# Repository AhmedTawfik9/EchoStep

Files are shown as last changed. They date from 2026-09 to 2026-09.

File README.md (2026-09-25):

# EchoStep – Feedback Device for Special Needs

EchoStep is a wearable assistive system developed.

The project is designed to support people with hearing impairments by detecting environmental sounds, estimating their direction and intensity, and converting this information into visual feedback on a wearable device.

## Features

- Real-time sound level detection using an Android smartphone
- Stereo-audio based sound direction estimation
- TDOA / GCC-PHAT based sound localization
- Classification of sound direction as LEFT, CENTER or RIGHT
- Sound intensity estimation
- Bluetooth Low Energy (BLE) communication
- Arduino Nano 33 BLE based wearable controller
- LED matrix / RGB visual feedback
- Step counter functionality
- Custom 3D-printed enclosure

## System Architecture

The system consists of three main components:

1. **Android SoundDetector App**
   - Captures audio from the smartphone microphones
   - Calculates sound level
   - Estimates sound direction using stereo audio
   - Uses TDOA and GCC-PHAT for direction estimation
   - Sends the processed information to the wearable device through BLE

2. **Arduino Wearable Device**
   - Based on the Arduino Nano 33 BLE
   - Receives sound information from the Android application
   - Displays sound direction and intensity using LEDs
   - Provides wearable feedback to the user
   - Includes step-counting functionality

3. **3D-Printed Enclosure**
   - Custom enclosure designed for the wearable electronics
   - Contains the Arduino, display/LED components and supporting hardware

## Repository Structure

```text
EchoStep/
├── android-app/     # Android SoundDetector application
├── arduino/         # Arduino firmware
├── 3d-models/       # 3D-printable enclosure files
├── README.md
├── LICENSE
└── .gitignore

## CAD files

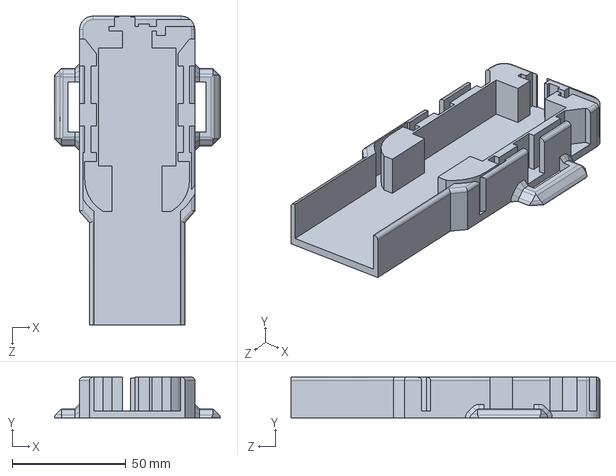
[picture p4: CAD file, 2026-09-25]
3D-Models/Base2.1.SLDPRT
73.1 x 18.0 x 136.0 mm

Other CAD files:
3D-Models/Base2.1.STL

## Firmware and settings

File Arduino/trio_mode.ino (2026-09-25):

/*
  Triple-Mode Wearable Feedback Device
  ----------------------------------------
  Three display modes on a single 8x8 MAX7219 matrix, cycled via the B14
  button (interrupt-driven):

    MODE_STEPS      - step-count progress (onboard IMU)          -> Mode1_Steps.hpp
    MODE_SOUND_BLE  - sound intensity via phone-assisted BLE      -> Mode2_SoundBLE.hpp
    MODE_MIC_ARRAY  - sound direction/intensity, onboard 2-mic    -> Mode3_MicArray.hpp

  Each mode lives entirely in its own file: its own tuning constants,
  state, and update logic, grouped together and documented at the top of
  that file. This file only owns shared hardware (the matrix, the
  button) and orchestration (mode enum, ISR, setup/loop, render dispatch)
  — see each Mode*.hpp file for that mode's specific tuning parameters
  and calibration notes.

  CORE DESIGN PRINCIPLE: every mode's data is updated EVERY loop
  iteration regardless of which mode is currently displayed. Only the
  final "push this mode's buffer to the matrix" step is gated on which
  mode is active (see renderActiveMode() and each mode's own Update()
  function). This keeps all three subsystems "live" in the background,
  so switching modes never loses data.

  The button uses a hardware interrupt only because it's an
  unpredictable, user-triggered event we don't want to risk missing
  (e.g. during the step mode's celebration delay() calls). The ISR
  itself only flips a flag; the actual mode switch and re-render happen
  in loop() — see onButtonPress() and the top of loop().

  Wiring:
  - MAX7219 matrix (SPI): VCC->5V, GND->GND, DIN->D11, CLK->D13, CS->D10
  - B14 button: one leg -> D2 (BUTTON_PIN below), other leg -> GND
    (uses internal pullup, so button press = LOW)
  - Two B03 microphones: MIC1 -> A6 (must be the RIGHT mic), MIC2 -> A7
    (must be the LEFT mic) — see Mode3_MicArray.hpp / SoundDirection.hpp
    for why this physical placement matters.

  NOTE ON MAX7219 POWER: if the matrix shows nothing, the Nano's 3.3V
  logic may be below the MAX7219's input-high threshold when it's
  powered at 5V. Try powering the matrix's VCC from 3.3V instead, or use
  a logic level shifter.
*/

#include <MD_MAX72xx.h>
#include <SPI.h>

// ---------------- MAX7219 matrix configuration ---------------- PAROLA_HW or GENERIC_HW or FC16_HW
#define HARDWARE_TYPE MD_MAX72XX::GENERIC_HW
#define MAX_DEVICES 1
#define CS_PIN 10
MD_MAX72XX mx = MD_MAX72XX(HARDWARE_TYPE, CS_PIN, MAX_DEVICES);

// ---------------- Display mode ----------------
enum DisplayMode { MODE_STEPS, MODE_SOUND_BLE, MODE_MIC_ARRAY, NUM_MODES };
DisplayMode currentMode = MODE_STEPS;

// ---------------- Button configuration ----------------
const int BUTTON_PIN = 2;
const unsigned long DEBOUNCE_MS = 200;
volatile bool modeChangeRequested = false;
volatile unsigned long lastInterruptTime = 0;

void onButtonPress() {
  unsigned long now = millis();
  if (now - lastInterruptTime > DEBOUNCE_MS) {
    modeChangeRequested = true;
    lastInterruptTime = now;
  }
}

// Forward declaration so the mode files (included below) can call this
// from their own Update() functions.
void renderActiveMode();

// ---------------- Mode implementations ----------------
// Each file is self-contained: its own tuning constants, state, and
// logic. See each file's header comment for details specific to that
// mode.
#include "Mode1_Steps.hpp"
#include "Mode2_SoundBLE.hpp"
#include "Mode3_MicArray.hpp"

void setup() {
  Serial.begin(115200);

  // Bounded wait for Serial Monitor rather than an infinite while(!Serial)
  // — lets the sketch proceed even if no Serial connection shows up,
  // instead of hanging forever. This is the ONE Serial wait for the whole
  // sketch; individual mode files do not repeat it.
  unsigned long serialWaitStart = millis();
  while (!Serial && (millis() - serialWaitStart < 3000)) {
    ;
  }

  bool matrixOK = mx.begin();
  mx.control(MD_MAX72XX::INTENSITY, MAX_INTENSITY);
  mx.clear();
  Serial.print("MAX7219 init: ");
  Serial.println(matrixOK ? "OK" : "FAILED");

  pinMode(BUTTON_PIN, INPUT_PULLUP);
  attachInterrupt(digitalPinToInterrupt(BUTTON_PIN), onButtonPress, FALLING);

  stepsSetup();
  soundBLESetup();
  micArraySetup();

  Serial.println("Ready. Starting in STEP mode.");
  renderActiveMode();
}

void loop() {
  // Handle a pending mode switch requested by the ISR
  if (modeChangeRequested) {
    modeChangeRequested = false;
    currentMode = (DisplayMode)((currentMode + 1) % NUM_MODES);

    Serial.print("Switched to mode: ");
    switch (currentMode) {
      case MODE_STEPS:     Serial.println("STEPS"); break;
      case MODE_SOUND_BLE: Serial.println("SOUND (BLE)"); break;
      case MODE_MIC_ARRAY: Serial.println("SOUND (MIC ARRAY)"); break;
      default: break;
    }
    renderActiveMode();
  }

  // ALWAYS update every mode's data, regardless of active mode
  stepsUpdate();
  soundBLEUpdate();
  micArrayUpdate();
}

// Pushes the currently active mode's buffer to the physical matrix.
// This is the ONLY place that writes to the matrix during normal
// operation (stepsCelebrateMilestone() is the sole deliberate exception,
// since it's a direct full-matrix flash effect gated on steps being
// active at the time it's called).
void renderActiveMode() {
  byte *buffer;

  switch (currentMode) {
    case MODE_STEPS:     buffer = stepMatrixState; break;
    case MODE_SOUND_BLE: buffer = soundBLEMatrixState; break;
    case MODE_MIC_ARRAY: buffer = micArrayMatrixState; break;
    default: return;
  }

  for (int row = 0; row < 8; row++) {
    mx.setRow(0, row, buffer[row]);
  }
}

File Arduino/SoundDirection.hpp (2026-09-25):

#ifndef SOUND_DIRECTION_HPP
#define SOUND_DIRECTION_HPP

#include <Arduino.h>
#include <math.h>
#include <stdint.h>

#include "Structures.h"

class SoundDirectionClassifier {
public:
    enum Direction { LEFT, CENTER, RIGHT };

    struct Result {
        Direction direction;
        float score;             // -1 = LEFT, +1 = RIGHT
        float confidence;        // 0..1, evidence strength
        float agreement;         // 0..1, spectral band agreement
        float correlation;       // -1..+1 normalized correlation peak
        float correlationScore;  // -1..+1 directional correlation score
        float delaySamples;      // positive = RIGHT, negative = LEFT
        uint8_t activeBands;
    };

    SoundDirectionClassifier()
        : _state(CENTER),
          _leftCandidateCount(0),
          _rightCandidateCount(0),
          _centerCandidateCount(0),
          _enterThreshold(0.30f),
          _leaveThreshold(0.15f),
          _directionPersistence(2),
          _centerPersistence(3),
          _correlationEnabled(true),
          _correlationWeight(0.35f),
          _spectralWeight(0.65f),
          _microphoneSpacingM(0.050f),
          _soundSpeedMps(343.0f),
          _maxCorrelationLag(4),
          _minCorrelationStrength(0.20f),
          _epsilon(1.0e-9f)
    {
        reset();

        for (uint8_t i = 0; i < MAX_BANDS; ++i)
            _centerBias[i] = 0.0f;

        _centerBias[0] = -0.28f;
        _centerBias[1] = -0.08f;
        _centerBias[2] = -0.37f;
        _centerBias[3] = -0.51f;
        _centerBias[4] = -0.09f;
    }

    // --------------------------------------------------------
    // Main update function.
    //
    // mic1/mic2:
    //     Already calibrated FrequencyMagnitude arrays.
    //
    // numBands:
    //     Number of valid frequency bands.
    //
    // bandWeights:
    //     Weights supplied by main.cpp.
    //
    // adcBuffer:
    //     Interleaved raw samples:
    //
    //       MIC1[0], MIC2[0],
    //       MIC1[1], MIC2[1],
    //       ...
    //
    // samplePairs:
    //     Number of samples PER microphone.
    //
    // sampleRate:
    //     ADC sample rate.
    // --------------------------------------------------------
    Result update(
        const FrequencyMagnitude* mic1,
        const FrequencyMagnitude* mic2,
        uint8_t numBands,
        const float* bandWeights,
        const int16_t* adcBuffer,
        uint32_t samplePairs,
        uint32_t sampleRate)
    {
        if (numBands == 0 || bandWeights == nullptr ||
            mic1 == nullptr || mic2 == nullptr) {
            return makeResult(0.0f, 0.0f, 0.0f, 0, 0.0f, 0.0f);
        }

        if (numBands > MAX_BANDS)
            numBands = MAX_BANDS;

        float weightedScore = 0.0f;
        float totalWeight = 0.0f;
        float balances[MAX_BANDS];

        for (uint8_t b = 0; b < numBands; ++b) {
            balances[b] = 0.0f;

            float m1 = mic1[b].magnitude;
            float m2 = mic2[b].magnitude;

            if (!isfinite(m1) || !isfinite(m2))
                continue;

            if (m1 < 0.0f) m1 = 0.0f;
            if (m2 < 0.0f) m2 = 0.0f;

            float energy = m1 + m2;
            float weight = bandWeights[b];

            if (weight <= 0.0f)
                continue;

            // Ignore bands below their configured noise floor.
            if (energy < _noiseThreshold[b])
                continue;

            float balance = (m1 - m2) / (energy + _epsilon);
            // Remove the empirically measured CENTER bias.
            balance -= _centerBias[b];
            balance = clamp(balance, -1.0f, 1.0f);

            balances[b] = balance;
            weightedScore += weight * balance;
            totalWeight += weight;
        }

        float spectralScore = 0.0f;
        uint8_t activeBands = 0;

        if (totalWeight > _epsilon) {
            spectralScore = weightedScore / totalWeight;

            for (uint8_t b = 0; b < numBands; ++b) {
                if (bandWeights[b] <= 0.0f)
                    continue;

                float m1 = mic1[b].magnitude;
                float m2 = mic2[b].magnitude;

                if (!isfinite(m1) || !isfinite(m2))
                    continue;

                if (m1 < 0.0f) m1 = 0.0f;
                if (m2 < 0.0f) m2 = 0.0f;

                if ((m1 + m2) >= _noiseThreshold[b])
                    activeBands++;
            }
        }

        spectralScore = clamp(spectralScore, -1.0f, 1.0f);

        // ----------------------------------------------------
        // Spectral band agreement.
        // ----------------------------------------------------

        float agreement = 0.0f;

        if (totalWeight > _epsilon && fabsf(spectralScore) > _epsilon) {
            float direction = spectralScore > 0.0f ? 1.0f : -1.0f;
            float agreementSum = 0.0f;

            for (uint8_t b = 0; b < numBands; ++b) {
                if (bandWeights[b] <= 0.0f)
                    continue;

                float m1 = mic1[b].magnitude;
                float m2 = mic2[b].magnitude;

                if (!isfinite(m1) || !isfinite(m2))
                    continue;

                if (m1 < 0.0f) m1 = 0.0f;
                if (m2 < 0.0f) m2 = 0.0f;

                if ((m1 + m2) < _noiseThreshold[b])
                    continue;

                float directionalAgreement =
                    balances[b] * direction;

                directionalAgreement =
                    clamp(directionalAgreement, 0.0f, 1.0f);

                agreementSum +=
                    bandWeights[b] * directionalAgreement;
            }

            agreement = agreementSum / totalWeight;
        }

        // ----------------------------------------------------
        // Cross-correlation.
        // ----------------------------------------------------

        float correlation = 0.0f;
        float correlationScore = 0.0f;
        float delaySamples = 0.0f;

        if (_correlationEnabled &&
            adcBuffer != nullptr &&
            samplePairs >= 8 &&
            sampleRate > 0) {

            calculateCorrelation(
                adcBuffer,
                samplePairs,
                sampleRate,
                correlation,
                correlationScore,
                delaySamples
            );
        }

        // ----------------------------------------------------
        // Combine spectral and correlation direction.
        //
        // Both features use the same convention:
        //
        //     -1 = LEFT
        //      0 = CENTER
        //     +1 = RIGHT
        // ----------------------------------------------------

        float finalScore = spectralScore;

        bool correlationUsable =
            _correlationEnabled &&
            fabsf(correlation) >= _minCorrelationStrength;

        if (correlationUsable) {
            float totalFeatureWeight =
                _spectralWeight + _correlationWeight;
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
